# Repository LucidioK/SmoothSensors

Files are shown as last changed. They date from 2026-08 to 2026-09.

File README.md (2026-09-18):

# SmoothSensors03

This is a simple robot that responds to these voice commands:

*  Go ahead
*  Go back
*  Turn right
*  Turn left
*  Stop
*  Calibrate (spins the robot in place to correct compass bias — see [Basic Functionality](#basic-functionality))
*  Point to <bearing> (North, Northeast, East, Southeast, South, Southwest, West, Northwest — turns the robot in place to face the requested absolute heading, using the calibrated compass — see [Basic Functionality](#basic-functionality))  
All its code is in this repository, including all files to 3D print its chassis.

[Here is a short video with it in action.](https://www.youtube.com/shorts/1sfNaSUcYxk)

## Bill of materials

* Arduino Uno Q
* NASTIMA 6V 6Ah LiFePO4 Battery with USB C Charge
* Arduino Modulino Motors ABX00114
* Arduino Modulino Buttons ABX00110
* Arduino Modulino Distance ABX00102
* Arduino USB-C Hub (8 in 1) TPX00241
* DC Electric TT Prewired Gear Motor Wheel Kit 3-6V Dual Shaft Geared
* I2C Qwiic Cable Kit Stemma QT Wire
* USB Camera Module 640x480 30FPS Wide Angle 170° HD Vision Module for Robot Building DIY Webcam Board for Arduino
* M2, M2.5 and M3 bolts.
* Caster whell, 50mm tall.

## Software

* [Arduino CLI](https://github.com/arduino/arduino-cli/releases)
* [Arduino App Lab](https://docs.arduino.cc/software/app-lab/)
* [VS Code](https://code.visualstudio.com/download)

## The chassis

Folder `cad` has the 3D model and the 3D print files for the chassis that accommodates all parts.

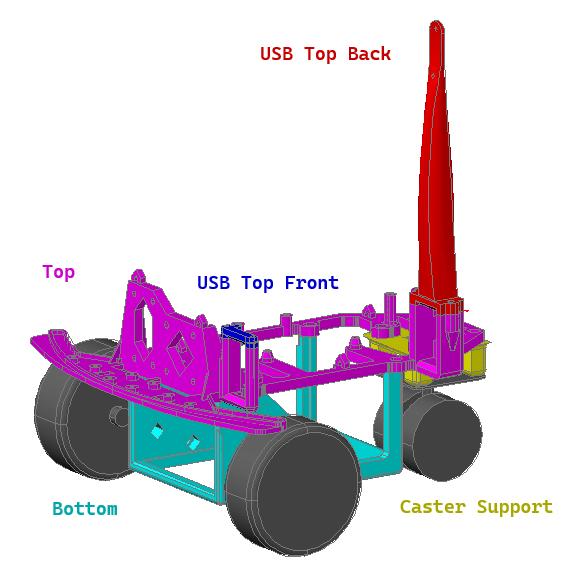
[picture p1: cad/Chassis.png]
Chassis


The chassis was optimized to use as little material and to print as fast as possible. As such, it is composed of five parts:

| Part | Part File | Description |
|---|---|---|
| Top | RobotChassis03Top.stl | where the Arduino and the sensors are attached. |
| Bottom | RobotChassis03Bottom.stl | where the battery and the motors are attached. |
| UsbB | RobotChassis03UsbB.stl | The top of the USB hub harness, back part, also where Mic and Camera should be attached. |
| UsbF | RobotChassis03UsbF.stl | The top of the USB hub harness, front part.  |
| Caster Support | RobotChassis03CasterSupport.stl | to be attached to the Top, then the caster wheel will be attached to. |

* File [RobotChassis03Split.dwg](cad/RobotChassis03Split.dwg) is the 3D model, it was done in AutoCAD.
* File [RobotChassis03.3mf](cad/RobotChassis03.3mf) is the Creality print file for all the parts in one print.
* File [RobotChassis03.stl](cad/RobotChassis03.stl) is the full assembled chassis as a single mesh, provided so it previews directly on GitHub (the split part files above don't render individually).
* File [Chassis.png](cad/Chassis.png) is the rendered preview image shown above.

## Repository structure

This is an [Arduino App Lab](https://docs.arduino.cc/software/app-lab/) project: an MCU-side sketch and a Linux-side Python app that run simultaneously on the Uno Q and talk to each other over RPC.

* `app.yaml` — the App Lab manifest that ties the `sketch/` and `python/` halves together into a single deployable app (`SmoothSensors03`).
* `SPEC.md` — the full project specification (hardware, architecture, behaviors, safety interlocks) for the robot, including parts not yet built.
* `PHASE1.md` — the current build phase broken into ordered, individually testable scenarios (non-vision voice commands, motors, safety), scoped down from `SPEC.md`.
* `test.py` — runs the whole test suite: `python/tests/` (always safe), then `sketch/tests/test_sketch_hardware.py` (a no-op dry run unless `--yes` is passed). Extra CLI args are forwarded to the sketch test, e.g. `python test.py --yes`.

### `sketch/` — MCU-side C++ program (Zephyr RTOS)

| File | Description |
|---|---|
| `sketch.ino` | Main entry point. Wires up the sensors/actuators, exposes `show_text` and `move` to Python over `Bridge`, and drives the main loop (record sensor samples every iteration, print status to the Serial Monitor once a second, auto-stop when an obstacle is closer than 10cm). Also handles the `calibrate` `move` command: delegates to `CombinedCalibration`, which runs motor calibration then compass calibration in sequence (replacing the former separate `calibrate_motors`/`calibrate_compass` commands). Also handles the 8 `point_*` `move` commands (one per bearing): a turn/settle/re-check loop closes on `SmoothCompass::getDirectionAngle()` until the heading is within ±8° of the target or an 8s timeout elapses, refusing to run (`e06`) unless `CompassCalibration` reports a calibration has already succeeded this boot. Also handles the `compass_mode` `move` command, delegating to `CompassMode`. |
| `SmoothDistance.h` | Wraps the `ModulinoDistance` (VL53L4 time-of-flight) sensor in a circular buffer that averages readings after dropping the min/max outlier, exposed via `getDistanceCm()`. |
| `SmoothMovement.h` | Same outlier-rejecting smoothing technique as `SmoothDistance.h`, applied to the `ModulinoMovement` IMU; exposes smoothed accelerometer and roll/pitch/yaw via `get(...)`. |
| `SmoothCompass.h` | Same outlier-rejecting smoothing technique, applied to the `Adafruit_LIS3MDL` magnetometer; exposes heading via `getDirectionAngle()`/`getDirectionBearing()`. Raw readings are hard-iron biased (onboard motor/battery/wiring magnetism), so it also tracks raw min/max during a calibration window (`startCalibration()`/`finishCalibration()`) to compute and apply an offset/scale correction. `getDirectionAngle()` now also drives the closed-loop absolute-heading turns behind the `point_*` commands, not just calibration. Includes a `recoverBus()` I2C bus-recovery guard run before any sensor transaction, to fail safely instead of hanging the board on a stuck bus. |
| `CompassCalibration.h` | Drives the motor-powered, gyro-closed-loop calibration spin, run as the second phase of the `calibrate` command: spins the robot in place via `RobotMotors`, integrating the IMU's `rz` to track rotation until it passes 380° (a 20° overshoot margin) or an 8s timeout elapses, then — if it actually rotated at least 300° — hands the spin off to `SmoothCompass::finishCalibration()` to compute the offset/scale correction. Fully self-contained: owns its own sensor reads and Monitor/LED reporting. |
| `MotorCalibration.h` | Runs as the first phase of the `calibrate` command: ramps turn power to find and store a reliable turn speed, plus each direction's steady-state rate and momentum-coast angle (used by `RobotMotors` to compensate point-to-bearing turns for overshoot). Fully self-contained, same shape as `CompassCalibration.h`. |
| `CombinedCalibration.h` | Sequences `MotorCalibration` then `CompassCalibration` behind the single `calibrate` command (GitHub issue #6) — pure orchestration, no sensor/display access of its own since both sub-features already own their own reporting. |
| `CompassMode.h` | Continuously displays the compass bearing on the LED matrix while active (GitHub issue #12). Cancelled by `SketchClass` whenever any other text is shown on the LED matrix. |
| `RobotMotors.h` | Wraps the `ModulinoMotors` dual H-bridge driver; translates command strings (`go_ahead`/`go_back`/`turn_right`/`turn_left`/`stop`) into motor drive calls and reports status via `getStatus()`. While `go_ahead`/`go_back` are driving, continuously reads the gyro's yaw rate and nudges a live per-wheel correction to hold a straight line against the free-swiveling rear caster's drift (GitHub issue #10). |
| `LedMatrixDisplay.h` | Wraps the Uno Q's built-in 8x13 LED matrix (`ArduinoLEDMatrix`) to print short (3-character) status codes, e.g. `rdy`, `ga`, `st`. |
| `sketch.yaml` | Pins the `arduino:zephyr` platform and exact versions for every Arduino library the sketch depends on (Modulino, RouterBridge, LSM6DSOX, LIS3MDL magnetometer, etc.), so profile-based builds don't depend on globally installed libraries. |
| `tests/test_sketch_hardware.py` | **Hardware-in-the-loop test — deploys to and restarts a real robot.** Runs `scripts/deploy.sh`/`deploy.ps1` to build+upload the sketch, then reads back `arduino-app-cli monitor` (the MCU's own Serial output) and `arduino-app-cli app logs` (the Python app's stdout — a separate stream, captured sequentially rather than concurrently so two SSH password prompts don't race) over SSH, asserting each sensor/motor class (`SmoothDistance`, `SmoothMovement`, `RobotMotors`) is reporting status without crashing the loop. Does nothing unless you pass `--yes`; see the file's docstring for usage and safety notes. |

### `python/` — Linux-side Python app (`arduino.app_utils` App framework)

| File | Description |
|---|---|
| `main.py` | App entry point. Polls `VoiceCommands` for a recognized command each loop iteration and forwards it to the MCU side via `Bridge.call("show_text", ...)` and `Bridge.call("move", ...)`. |
| `VoiceCommands.py` | Offline voice recognition using Vosk, grammar-constrained to the wake word "robot" followed by one of the move commands (`go ahead`/`go back`/`turn right`/`turn left`/`stop`/`calibrate`/`compass mode`/`point to north`/`point to northeast`/`point to east`/`point to southeast`/`point to south`/`point to southwest`/`point to west`/`point to northwest`). Captures audio by spawning `arecord` as a subprocess (not PyAudio, since the board's venv has no C compiler to build native extensions) and feeds the raw PCM to the recognizer. |
| `requirements.txt` | Python dependencies for the Linux side (currently just `vosk`, the offline speech recognizer). |
| `model/` | *(not checked in, gitignored)* The Vosk speech model, tens of MB. Uploaded once by `scripts/deploy.sh` the first time it's missing on the board, then left alone on subsequent deploys. |
| `tests/test_python_app.py` | Unit tests for `VoiceCommands.py` and `main.py`. Runs off-board by stubbing `vosk`, `arduino.app_utils`, and the `arecord` subprocess. Run with `python -m unittest discover -s python/tests -v`. |

### `scripts/` — deploy and diagnostic tooling

| File | Description |
|---|---|
| `deploy.sh` | Pushes `sketch/`, `python/` (except `python/model/`), and `app.yaml` to the board over `tar`+`ssh`, then restarts the app via `arduino-app-cli`. Run from Linux/Mac/WSL. |
| `deploy.ps1` | Windows PowerShell equivalent of `deploy.sh`; auto-detects the board's IP address. |
| `setup_ssh_key.py` | Sets up passwordless SSH access to the board (the actual "ssh-copy-id" step — reuses `~/.ssh/id_ed25519` if you have one, otherwise generates a dedicated key, then appends the public key to the board's `~/.ssh/authorized_keys`). Run once before using `deploy.sh`/`deploy.ps1`; prompts for the board's password one last time. Safe to re-run. |
| `diagnose_usb_mic.sh` | Diagnoses (and, with `--fix`, attempts to repair) USB host / microphone enumeration problems on the board's Linux side — e.g. forcing the board's dual-role USB-C port into host mode so a hub/mic enumerates correctly. Must be run **on the board**, not the PC (it inspects local kernel/sysfs USB state). Can be piped over SSH without copying it to the board first: `ssh <board-user@host> 'bash -s' -- --fix < scripts/diagnose_usb_mic.sh`. |

## If you are using WSL (Windows System for Linux)

WSL runs in a VM without full access to the network.

As such, there is one Arduino CLI command that does not work on WSL: 

```bash
arduino-cli board list
```

If you are in Windows using WSL, you will need to run that command in a Powershell/cmd prompt.

## How to deploy

1. First, you need to initialize the Arduino board. Make sure you followed the [Initial Setup instructions](https://docs.arduino.cc/software/app-lab/setup/overview) for [Single Board Computer](https://docs.arduino.cc/software/app-lab/setup/standalone) mode.
1. After your Arduino Q is connected to your network, you will always use it through the network, the provided deploy scripts assume the board is already network bound.
1. Set up passwordless SSH access to the board (the deploy scripts call `ssh` non-interactively, which doesn't work with password auth): run `python scripts/setup_ssh_key.py` once (or `python scripts/setup_ssh_key.py arduino@<board-ip>` if it's not at the default address). You'll be prompted for the board's password one last time.
1. About the board's IP address:
   1. If you are using Windows with Powershell, you can use `scripts/deploy.ps1`, it automatically detect the board's IP address.
   1. Otherwise, you will need to discover the board's IP address and configure `scripts/deploy.sh` to point to the address:
      1. If you are using WSL, open a Powershell command prompt, if you are on Linux or Mac, open a command prompt.
      1. Run:
         ```
         arduino-cli board list
         ```
      1. If your robot is on and connected to the same network as your computer, you will see an output similar to this:
         ```
         Port       Protocol Type              Board Name    FQBN                Core
         10.0.0.221 network  Network Port      Arduino UNO Q arduino:zephyr:unoq arduino:zephyr
         ```
      1. The four numbers under `Port` are the IP address from your robot.
      1. Edit `scripts/deploy.sh` and replace the IP in this line with your robot's IP address:
         ```
         BOARD_IP="${1:-${BOARD_IP:-10.0.0.195}}"
         ```
      1. Save and close `scripts/deploy.sh`.
4. Now you can deploy the application:
   1. On Windows:
      1. Open a Powershell command prompt, 
      1. Go to the folder where you cloned this repository,
      1. Execute:
         ```powershell
         ./scripts/deploy.ps1
         ```
   1. On Linux/Mac/WSL
      1. Open a Powershell command prompt, 
      1. Go to the folder where you cloned this repository,
      1. Execute:
         ```bash
         ./scripts/deploy.sh
         ```

## Basic Functionality

```mermaid
stateDiagram-v2
    [*] --> Ready
    Ready --> GoAhead: Voice detected go ahead
    Ready --> GoBack: Voice detected go back
    Ready --> TurnRight: Voice detected turn right
    Ready --> TurnLeft: Voice detected turn left          
    Ready --> Calibrate: Voice detected calibrate
    Ready --> Point: Voice detected point to bearing
    Ready --> CompassMode: Voice detected compass mode
    GoAhead --> Stop: Voice detected STOP or distance less than 10cm
    GoBack --> Stop: Voice detected STOP or distance less than 10cm
    TurnRight --> Stop: Voice detected STOP or distance less than 10cm
    TurnLeft --> Stop: Voice detected STOP or distance less than 10cm
    Calibrate --> Ready: Spin reaches 380° or 8s timeout elapses
    Point --> Ready: Heading reaches target or 8s timeout elapses
    CompassMode --> Ready: Any other text shown on the LED matrix
    Stop --> Ready

```

## Error codes

When something goes wrong, the LED matrix shows a short `eN` code instead of the usual `ok`/command-echo status. Meanings:

| Code | Meaning |
|---|---|
| `e1` | The motors failed to initialize at startup, or a voice command arrived before/without them being ready. |
| `e2` | `robot calibrate` was requested, but the compass, movement sensor, or motors aren't initialized. |
| `e3` | A calibration spin finished but didn't detect enough rotation (or a wide enough magnetic swing) to compute valid correction values — most likely the robot didn't actually spin (stuck, lifted, or interrupted too early). |
| `e4` | `robot point to <bearing>` timed out (8 seconds) before the robot's heading reached the target bearing. |
| `e5` | `robot point to <bearing>` was requested, but the compass, movement sensor, or motors aren't initialized. |
| `e6` | `robot point to <bearing>` was requested before any compass calibration has succeeded since the robot last booted — run `robot calibrate` first. |
| `e7` | `robot calibrate` was requested, but a required sensor/motor isn't initialized (movement sensor or motors). |
| `e8` | `robot calibrate`'s motor calibration turn-power ramp failed to detect movement. |
| `e9` | `robot compass mode` was requested, but the compass sensor isn't initialized. |

`e01` is reserved in `SPEC.md` for a "find and follow \<object\>" voice command that isn't implemented yet, so it can't appear on the robot today.

## Known issues

1. (Arduino default behavior) the application must be redeployed every time the board is restarted.
1. When the robot is moving, due to the noise of the motor, the voice commands are not well understood. You need to talk much louder or close to the mic, depending on the quality of the microphone you are using. This has been greatly mitigated with the new USB
1. After the robot detects it is in less than 10 centimeters of some obstacle, it does not move. You say `robot go ahead` and it will move for half a second, at the most. In that case, place your hand in front of the distance sensor and move away. 
1. I am using very low quality motors, so some motors move faster than others despite being fed the same tension and current. I recommend you buy many motors, then test them and get motors with similar RPM when fed 5V.

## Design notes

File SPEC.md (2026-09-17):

# SmoothSensors Robot — Specification (Draft v1)

Status: DRAFT — under active review. Items marked TBD still need a decision before the phase that depends on them.

## 1. Purpose

An autonomous, wheeled robot that responds to voice commands, including finding and following an object (e.g. a person, a car, a cat) using onboard computer vision. No manual/remote-control mode in v1 — voice is the only control input. All commands are prefixed with the wake word "robot"; any speech not starting with "robot" is ignored.

## 2. Hardware

| Component | Role | Status |
|---|---|---|
| Arduino UNO Q | Dual-brain controller: Qualcomm QRB2210 (Linux, quad-core Cortex-A53 @ 2GHz, Adreno GPU) + STM32U585 (Zephyr RTOS, Cortex-M33) | Have it |
| Modulino Distance | Front-facing time-of-flight distance sensor | Wired, code exists (`SmoothDistance.h`) |
| Modulino Movement | IMU (accelerometer + gyro) | Wired, code exists (`SmoothMovement.h`) |
| Modulino Motors | MAX22211 dual H-bridge driver, 2 DC motors, differential drive, 5–24V/3.8A per channel motor supply, I2C/Qwiic control. Has configurable current-drive regulation (ITRIP, set via REFA/REFB resistors, up to 3.8A) — used to current-limit each motor channel, see Power row below. | Have it, not yet wired |
| Motors | [TT gear motor wheel kit](https://www.amazon.com/dp/B098Q1BCX5) (generic "TT motor," 1:48 gearbox, dual shaft, 69mm wheels). Standard TT motor specs: **rated 3–6V**, ~150mA no-load current per motor, ~1.1–1.5A stall current per motor (varies with voltage), ~200 RPM / 0.8 kg·cm stall torque at 6V. | Chosen |
| Magnetometer (LIS3MDL) | `"robot turn right/left N degrees"` still uses relative gyro dead-reckoning, not the compass (see §4). But absolute heading **is** now used, for `"robot point to <bearing>"` (§4c) — a real v1 use case, not deferred as originally planned (see §7 item 2). | **Wired, calibrated, and in active use.** `sketch/SmoothCompass.h` is wired into `sketch.ino`/the RPC surface and reads real hardware (no boot-hang — the `recoverBus()` guard holds). Raw headings were hard-iron biased (~3x Earth's field, confirmed empirically) until the motor-driven, gyro-closed calibration spin (§4b) was added and run — calibrated headings are now accurate enough to drive closed-loop turns (§4c). |
| USB camera | Front-facing; dual purpose: (a) input to onboard object-detection model, (b) live view streamed to a human over the local network. No built-in mic. | Physically present, not yet wired |
| Microphone | Captures voice commands | Mini USB microphone, attaches to the USB-C hub alongside the camera. Plugs into the Linux side, no custom MCU-side driver work. Purchased. **STT engine: Vosk** (offline, on-device) — no network dependency for core voice commands, lightweight enough for the QRB2210. |
| USB-C hub | The UNO Q has exactly **one USB-C port and no built-in USB-A ports**, so the camera and mic can't both plug in directly — a hub is required. Recommendation: **Arduino's official 8-in-1 USB-C hub for UNO Q** (USB-A 2.0, USB-A 3.0, HDMI, Ethernet, and — critically — **power delivery passthrough**, so the board still receives power through the hub while the camera and mic occupy its USB-A ports). A hub without PD passthrough would leave the board without a power path once the port is used for peripherals. | Purchased |
| Onboard LED matrix | Built into the UNO Q (8×13, 104 LEDs), driven by the STM32 MCU via the `Arduino_LED_Matrix` library. Used as the robot's only feedback display — see §4. | Built-in, have it |
| Chassis | Current: prototype. Target: 3D-printed. | Tracked as a separate design track (own mini-spec: dimensions, mount points, clearances) once electronics layout is settled — not part of this software spec. |
| Power | **Two separate rails**: one for Uno Q logic (delivered via the USB-C hub's power passthrough), one dedicated battery+regulator feeding the Modulino Motors' screw terminals directly. Avoids brownouts from motor current sagging the logic supply. Mitigation: set the MAX22211's ITRIP current limit to ~1.5A per channel (matching the motors' rated stall current) to cap heat/mechanical stress during stall. No PWM duty-cycle cap needed — the UBEC (below) holds motor rail voltage at a clean, fixed 6.0V regardless of battery charge state, so the driver never sees more than the motors' rated 6V. | [NASTIMA 6V 6Ah LiFePO4](https://www.amazon.com/dp/B0FD3SZFXF/) (2000+ cycles, built-in BMS, 10A max continuous discharge — well above the ~3A worst-case combined motor stall current) feeding a [Hobbywing 5A UBEC](https://valuehobby.com/hobbywing-5a-ubec-high-voltage.html) (switching buck regulator, output fixed to 6.0V, 5A continuous/15A instantaneous, >90% efficient) wired between the battery and the Modulino Motors' screw terminals. Raw battery voltage swings ~5–7.3V across its charge cycle (LiFePO4 cells read above 6V nominal near full charge); the UBEC clamps that to a steady 6.0V so the motors (rated 3–6V) never see an overshoot, eliminating the need for a software PWM cap. Battery-to-UBEC wiring: solder a cable from the NASTIMA's output connector to the UBEC input directly — no off-the-shelf connector match needed. Rejected earlier: [WAVYPO 9V 1300mAh Li-ion](https://www.amazon.com/dp/B0BC8P2TS6) — reviews report its internal boost converter caps steady-state output around ~100mA, far below driving current needs. | Purchased |
| Motor voltage regulator | [Hobbywing 5A UBEC](https://valuehobby.com/hobbywing-5a-ubec-high-voltage.html) — steps the LiFePO4 battery's raw ~5–7.3V down to a fixed, regulated 6.0V for the motor rail. See Power row. | Purchased |

## 3. System architecture

Two-brain split, mirroring the UNO Q hardware:

- **MCU side** (`sketch/`, Zephyr, real-time) — owns the Modulino I2C bus: Distance, Movement, Motors (Magnetometer deferred to phase 2, see §2). Responsible for low-level motion primitives (drive, turn-by-degrees, stop) and **hard safety interlocks** (tilt-stop, proximity-stop), enforced locally so they still fire even if the Linux side is slow or busy. Exposes primitives to the Linux side over RPC (extending the existing but currently-empty `get_sensor_values()` bridge).
- **Linux side** (`python/`, Debian, "brain") — owns the camera, microphone, speech-to-text (Vosk, offline), object-detection model, the local-network video stream server, and the high-level behavior loop (filter for the "robot" wake word → interpret voice command → decide behavior → issue motion requests to the MCU side). Never drives motors directly.

**Why split safety this way**: if proximity-stop and tilt-stop lived only in Python, a slow CV inference frame could delay a stop. Putting them on the MCU side is defense-in-depth — the robot stops even if the "brain" is momentarily busy.

## 4. Core behaviors

- **Voice-driven, fully autonomous.** No joystick/remote mode in v1.
- **Wake word:** every command must start with the word "robot" (e.g. "robot stop", "robot find and follow cars"). Any recognized speech that doesn't start with "robot" is discarded — no action taken, no side effects.
- **v1 command vocabulary:**
  - `"robot find and follow <object>"` → enter autonomous vision-following mode targeting the named object class (e.g. "cats", "people", "cars" — not limited to a fixed list, see below)
  - `"robot stop"` → halt all motion, exit any active mode
  - `"robot go forward"` → drive straight forward in a line
  - `"robot turn right <N> degrees"` / `"robot turn left <N> degrees"` → closed-loop turn using gyroscope feedback: integrate the Modulino Movement IMU's Z-axis rotation rate (`rz`, already exposed by `SmoothMovement::get()`) over time to track cumulative rotation since the turn started, stop once it reaches `N` degrees. No magnetometer needed — v1 turns are relative (dead-reckoned), not absolute-heading; drift over the few seconds a turn takes is negligible. See §2, Magnetometer row.
  - `"robot calibrate"` → triggers motor calibration followed by the compass calibration spin, in that sequence (MCU-side `move("calibrate")` command) → see §4b.
  - `"robot point to <bearing>"`, where `<bearing>` is one of North/Northeast/East/Southeast/South/Southwest/West/Northwest → closed-loop turn using the live, calibrated compass heading (not gyro dead-reckoning) to rotate until the robot faces the requested absolute bearing → see §4c.
  - This is the full v1 vocabulary planned so far; more can be added in a later phase once the core loop is proven.
  - No backward-motion command in v1 — the only distance sensor is front-facing, so there's no obstacle protection for reversing. Revisit once a rear-facing sensor is added.
- **Go forward:** drives continuously until `"robot stop"` is heard or a safety interlock fires — same rule as following mode. No fixed-distance mode in v1.
- **Object-following mode:**
  - The target object name is parsed out of the command (the words after "find and follow") and mapped to a class the onboard object-detection model recognizes. A single general-purpose pretrained multi-class model (e.g. one trained on COCO, which already includes person, car, cat, dog, and more) covers this without per-object custom training — good fit given the requirement isn't cat-specific.
  - Name normalization: lowercase the parsed noun, strip a trailing "s" (handles "cats"→`cat`, "cars"→`car`, "dogs"→`dog`, etc.), with a small hand-written exception table for irregulars (starting with "people"→`person`), extended as new irregular cases come up. No NLP library dependency.
  - If the requested object isn't a class the detector supports (e.g. "robot find and follow squirrels"), display error `e01` on the LED matrix (see §4a) instead of attempting the behavior.
  - Onboard object detection locates the target class in the camera frame; robot steers to keep it centered and drives toward it.
  - Stop distance from the target: reuses the proximity-stop threshold (§5) — no special-cased "following distance," just don't get closer than the general obstacle-stop distance.
  - Multiple matching objects in frame: follow whichever detected instance has the largest bounding box (a simple proxy for "closest/most prominent," needs no extra hardware); ignore the rest.
  - Lost target: rotate in place toward the side the target was last seen, sweeping up to a full 360°, to search and reacquire. If the target isn't reacquired by the time the sweep completes, stop and await a new voice command — the full rotation itself bounds the search, no separate timeout needed.
- **Live camera view:** streamed over the local Wi-Fi network for a human to watch. Observation only — never used as a control input by the human.

## 4a. Feedback display (onboard LED matrix)

The robot's only user-facing feedback channel in v1 is the built-in LED matrix (no speaker/TTS in scope):

- **Understood a command:** display `ok`.
- **Any error:** display `eNN`, where `NN` is a two-digit error code.
- **Error code registry** (extend as new error cases are identified during implementation):
  | Code | Meaning |
  |---|---|
  | `e01` | Requested object class not recognized by the detector |
  | `e02` | Compass calibration requested but a required sensor/motor isn't initialized |
  | `e03` | Compass calibration finished but the magnetic sample span was too small to compute valid offsets (likely didn't actually rotate) |
  | `e04` | Point-to-bearing timed out (8s) before reaching the target heading within tolerance — see §4c |
  | `e05` | Point-to-bearing requested but a required sensor/motor isn't initialized (mirrors `e02` for the point-to command) |
  | `e06` | Point-to-bearing requested before any compass calibration has succeeded this boot — see §4c |
- **In-progress status codes** (extend as new commands are added): `rdy` (ready at startup), `ga`/`gb`/`tr`/`tl`/`st` (go ahead / go back / turn right / turn left / stop, echoing the recognized command), `cal` (calibration succeeded), `pN`/`pNE`/`pE`/`pSE`/`pS`/`pSW`/`pW`/`pNW` (point-to-bearing in progress, shown immediately on command receipt — see §4c).
- **Persistence:** the matrix shows the result of the last command and stays that way until the next command overwrites it — no auto-clear timer. Before the first command is ever received, the matrix is blank.

Since the LED matrix hardware is driven by the MCU (`Arduino_LED_Matrix`) but recognition/parsing happens on the Linux "brain," the Linux side will need to request a display update from the MCU side over RPC (alongside the existing motion-primitive RPC calls in §3).

## 4b. Compass calibration (motor-driven, gyro-closed)

The magnetometer readings are dominated by a hard-iron offset from onboard magnetic material (motors, battery, wiring) — raw headings only sweep a narrow ~40° arc instead of the full circle. Calibration removes this by finding the offset (and axis scale, for soft-iron distortion) from a full-circle sample of raw x/y readings, then correcting all future readings against it.

- **Trigger:** voice command `"robot calibrate"` (added to the Vosk grammar in `python/VoiceCommands.py` alongside the existing move commands), which calls the MCU-side `move("calibrate")` RPC (same RPC surface as `go_ahead`/`turn_right`/`turn_left`/`stop`, see §3) — this runs motor calibration first, then the compass calibration spin described below, as a single sequenced command.
- **Rotation:** self-driven via the existing motors, not manual. Closed-loop on the gyro, using the same `rz`-integration dead-reckoning technique described for `turn right/left N degrees` (§4) — this calibration spin is the first actual implementation of that technique in the sketch; `turn right/left N degrees` itself remains unimplemented (§4 documents the intended approach only). Accumulate rotation until it passes **380°** (a 20° overshoot margin over a full circle, to absorb gyro lag/undershoot so no heading is missed), then stop. A **hard timeout (8s)** force-stops the motors regardless of accumulated angle, guarding against the robot being stuck or lifted mid-spin, where `rz` would never accumulate.
- **Safety interlock:** the proximity-stop check (§5) is suspended for the duration of calibration — it's a pure in-place spin, not forward motion — and restored once calibration ends (success or timeout).
- **Sampling:** raw magnetometer x/y are tracked (min/max per axis) throughout the spin, alongside the existing smoothed ring buffer.
- **Result:** hard-iron offset (`(max+min)/2` per axis) and soft-iron scale (`mean_radius / ((max-min)/2)` per axis) are computed once the spin ends, applied immediately in RAM (so `SmoothCompass::getDirectionAngle()` is corrected for the rest of that boot), and printed to the Monitor for the operator to copy into `SmoothCompass.h` as permanent defaults — there's no flash/EEPROM persistence in this codebase, so an in-RAM-only calibration is lost on reboot until hardcoded.
- **Not addressed by this calibration:** the dynamic field from motor current while driving (differs from the field during the calibration spin itself), and any residual mounting-rotation/declination offset — both remain open, see §7.

## 4c. Point to bearing (closed-loop compass turn)

Turns the robot in place until it faces a requested absolute bearing, using the live, calibrated compass heading as feedback rather than gyro dead-reckoning (unlike §4b's calibration spin, which has no absolute reference to close the loop against, this command's whole purpose is to use one).

- **Trigger:** voice command `"robot point to <bearing>"` for one of the 8 primary bearings (North/Northeast/East/Southeast/South/Southwest/West/Northwest), added to the Vosk grammar in `python/VoiceCommands.py`. Each maps to a distinct RPC command string: `point_north`, `point_northeast`, `point_east`, `point_southeast`, `point_south`, `point_southwest`, `point_west`, `point_northwest`. Target degrees: N=0°, NE=45°, E=90°, SE=135°, S=180°, SW=225°, W=270°, NW=315°.
- **Precondition, runtime-enforced:** a compass calibration (§4b) must have succeeded at least once since boot. This is checked in code (not just documented) — a `point_*` command issued before any successful calibration this boot is refused with error `e06`, rather than silently running against whatever `SmoothCompass.h`'s hardcoded defaults happen to be.
- **Display:** immediately on receiving the command (before the turn starts), the LED matrix shows `p` followed by the bearing's abbreviation (`pN`, `pNE`, `pE`, `pSE`, `pS`, `pSW`, `pW`, `pNW`) — this is the Python-side `main.py` `_led_codes` entry, shown the same way `ga`/`tr`/etc. are today. On completion, the MCU overwrites it with `ok` (reached the target) or `e04` (timed out).
- **Direction decision:** compute the signed angular error (target − current heading, normalized to `(-180°, 180°]`). Turning right (`turn_right`) increases the reported heading (confirmed empirically against real hardware); a positive error turns right, a negative error turns left — the shorter way around, never more than 180° of rotation.
- **Turn/settle/re-check loop, not a single pass:** `SmoothCompass::getDirectionAngle()` is a 32-sample trim-mean, so while the robot is actively spinning the reported heading lags the true one — stopping the instant the raw error looks small would systematically overshoot. Instead: turn until the error is within tolerance (**±8°**) or its sign flips (guards against jumping past the tolerance band between loop iterations), stop the motors, wait for the ring buffer to refill with post-stop samples, then re-read the heading — if still outside tolerance, turn again (opposite direction if needed) rather than declaring success on a stale reading.
- **Safety timeout:** **8 seconds**, bounding the whole operation including every turn/settle/re-check cycle — guards against a bad calibration, an unreachable target, or oscillation at the tolerance boundary. Times out to `e04`.
- **Safety interlock:** proximity-stop (§5) is suspended for the duration, same reasoning as §4b — it's a pure in-place rotation, and the interlock's own `move("stop")`/LED-overwrite behavior would otherwise cancel the turn and stomp the `pN`-style display.
- **Cancellation:** any other `move()` command received while a point-to turn is in progress cancels it immediately (mirrors §4b's calibration-cancellation behavior). Re-issuing the same bearing while already turning toward it is a no-op (the turn continues); a different bearing restarts the turn toward the new target.
- **Not addressed:** a turn speed independent of the fixed drive speed used elsewhere (`RobotMotors`'s `DRIVE_SPEED`) — if physical testing shows the tolerance/settle values above don't converge reliably, a slower turn speed for this command specifically is the likely next step, deferred until shown necessary.

## 5. Safety (always active, MCU-enforced, overrides any in-progress command)

- **Proximity stop:** if the front distance sensor reads below a threshold, stop forward motion immediately. Threshold: **5 cm**.
- **Tilt stop:** IMU is monitored continuously (not just at startup); if tilt exceeds a threshold at any time, including mid-drive, stop all motion immediately. Threshold: **30°, provisional** — ships as-is in phase 1 (the chassis is built during phase 1, but calibrating this value is deliberately sequenced as a phase 2 activity, not blocked on anything from phase 1). **Phase 2 calibration:** physical test, tilting the assembled robot degree by degree until it tumbles, to find the real threshold — reusing the 30° provisional value until then.

## 6. Explicitly out of scope for v1

- Manual/remote teleoperation
- Camera used for anything beyond object-detection + human viewing
- Following objects outside the detector's supported classes
- Voice commands not prefixed with "robot"
- Chassis CAD (separate track)

## 7. Open items still needing a decision

1. Chassis dimensions/CAD (separate track, own spec)
2. ~~Whether v1 ever needs absolute heading (magnetometer) beyond relative turn-by-degrees~~ — resolved: yes, `"robot point to <bearing>"` (§4c) is a real v1 use case, built on the calibrated compass from §4b. Still open: a mounting-rotation/declination trim constant, and whether motor-current drift while actively driving needs separate handling (§4b's "not addressed" list) — neither has caused an observed problem yet since point-to only turns in place with motors idle otherwise
3. Final tilt-stop threshold — deferred to phase 2 by choice (empirical tumble test on the assembled robot), not blocked on chassis geometry since phase 1 builds the chassis
4. `"robot find and follow <object>"` (camera + onboard object detection) — deferred out of phase 1; camera isn't wired and no detection model is chosen yet. See `PHASE1.md` for phase 1's actual scope.
5. ~~Whether the calibration spin (§4b) should be exposed as a voice command~~ — resolved: yes, `"robot calibrate"` (§4/§4b)
6. Whether calibration constants need persistent (flash/EEPROM) storage, or hardcoding into `SmoothCompass.h` after each physical remounting remains acceptable

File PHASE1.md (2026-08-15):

# SmoothSensors — Phase 1

Status: DRAFT. Scope agreed 2026-08-14: non-vision commands only (`stop`, `go forward`, `turn <left|right> <N> degrees`), audio input, and LED matrix feedback, all backed by the MCU-side safety interlocks. No magnetometer, no camera/object-detection (`"find and follow"`) — those are deferred to a later phase (see `SPEC.md` §7). This file assumes `SPEC.md` as the source of truth for behavior/thresholds and only breaks it into buildable, testable steps.

Scenarios are ordered by dependency — each one after #2 can be built and manually tested standalone before the next.

## 1. Robot has an assembled physical chassis

- Gather real-world dimensions for every component that needs mounting, per `SPEC.md` §2: UNO Q board footprint, Modulino Motors module, TT motor + 69mm wheel kit, NASTIMA battery pack, Hobbywing UBEC, USB-C hub, USB camera, microphone, Modulino Distance sensor (needs a clear forward-facing view)
- Design the chassis as parametric FreeCAD Python scripts (`cad/`), driven by those dimensions — 4 bolted parts: top plate (sensors + UNO Q), battery box, and two motor mounts (left/right, below the battery)
- Render/export the design to STL via `cad/build_all.py` (`freecadcmd cad/build_all.py`)
- Obtain the 3D-printed parts (local printer or a print service)
- Assemble the chassis: mount the UNO Q board, Modulino Motors + motors/wheels, battery + UBEC, USB-C hub, camera, microphone, Distance sensor
- Basic tests: confirm physical fit (no interference between mounted parts, wheels turn freely by hand), confirm the chassis sits flat and stable at rest, confirm the board still boots and Distance/Movement sensors still read correctly once everything is mounted (checks for interference introduced by assembly, e.g. metal/wiring near the sensors)

## 2. Robot's motors are wired and powered

- Wire the Modulino Motors' screw terminals to the NASTIMA LiFePO4 battery via the Hobbywing UBEC, per `SPEC.md` §2 (Power row)
- Set the MAX22211's ITRIP to ~1.5A/channel via the REFA/REFB resistors
- Power on and confirm the board still boots normally and the Distance/Movement sensors still read correctly with the motor rail connected (check for brownout or I2C interference from motor switching noise)
- Bench-test: each wheel spins in both directions at a low duty cycle, driven by a throwaway test sketch (not the real primitives yet) — confirms wiring polarity and the driver chip before building on top of it

## 3. Robot's brain and controller can talk to each other

- Define the RPC message contract between `python/` and `sketch/` for: motion commands (`stop`, `driveForward`, `turn(direction, degrees)`) and LED display requests (`ok`, `eNN`)
- Implement the MCU-side RPC handlers in `sketch.ino`, extending the currently-empty `get_sensor_values()` bridge pattern
- Implement the Linux-side RPC client calls in `python/`
- Round-trip test: call a trivial RPC method from Python, confirm the MCU receives it and responds (e.g. echo or LED blink)

## 4. Robot stops on command

- Implement the `stop()` motion primitive on the MCU side (zero both motor channels)
- Wire it to the RPC handler from scenario 3
- Manual test: trigger `stop` via a hardcoded Python script call, confirm motors halt

## 5. Robot drives forward on command

- Implement the `driveForward()` motion primitive (both motors, same direction and duty cycle)
- Wire it to its RPC handler
- Manual test: trigger via script, confirm straight-line forward motion, confirm a follow-up `stop` call halts it

## 6. Robot turns left/right by a given number of degrees on command

- Confirm on real hardware whether `SmoothMovement`'s `rz` (from `_movement.getYaw()`) is an angular *rate* (°/s, as the code comment in `SmoothMovement.h` claims) or an already-integrated absolute angle — this determines whether the primitive needs to do its own time integration or can just read a running value. (No Modulino library source was available locally to confirm ahead of time.)
- Implement a dead-reckoned `turn(direction, degrees)` primitive: track cumulative rotation since the turn started (integrating `rz` over elapsed time if it's a rate) until it reaches the requested degrees, then stop
- Wire it to its RPC handler (direction + degrees as parameters)
- Manual test: trigger `turn right 90`, verify actual rotation against a physical reference mark (e.g. tape line on the floor), tune for overshoot/settling error

## 7. Robot stops automatically when something gets too close

- Implement a continuous MCU-side proximity check (5cm threshold, `SPEC.md` §5) that overrides any in-progress motion primitive, independent of RPC command cadence
- Manual test: drive forward via scenario 5, place an obstacle within 5cm, confirm the robot stops on its own with no Python-side involvement

## 8. Robot stops automatically when it tips too far

- Implement a continuous MCU-side tilt check using the existing `SmoothMovement` accelerometer data, provisional 30° threshold (`SPEC.md` §5) — this value ships as-is in phase 1; the degree-by-degree tumble test to find the real threshold is a phase 2 activity, not phase 1
- Same override behavior as scenario 7
- Manual test: tilt the assembled chassis past the (provisional) threshold mid-drive, confirm autonomous stop

## 9. Robot shows simple status messages on its LED matrix

- Add an `Arduino_LED_Matrix`-based display helper on the MCU side implementing `SPEC.md` §4a (`ok`, `eNN`, persists until overwritten, blank before the first command)
- Add the MCU-side RPC handler for display requests (from scenario 3's contract)
- Wire the Linux-side RPC call
- Manual test: trigger `ok` and a sample `eNN` from Python, confirm the matrix updates and persists

## 10. Robot receives orders by audio

- Integrate Vosk (offline STT) into `python/`: model selection/download, ALSA/PyAudio capture pipeline
- Continuous transcript loop; discard any utterance not starting with the wake word "robot" (`SPEC.md` §4)
- Command parser mapping recognized text to the phase 1 command set (`stop`, `go forward`, `turn <left|right> <N> degrees`) — reuse the object-name-normalization approach from `SPEC.md` §4 as a pattern, but only wire the non-vision commands now
- Any command outside the phase 1 set (including `"find and follow"`, deferred per scenario scope) or anything unparseable → trigger `eNN` on the LED matrix (scenario 9) instead of attempting the behavior
- Wire parsed commands to the RPC calls from scenarios 4–6
- Manual test: speak each phase 1 command aloud, confirm correct motion + LED feedback end-to-end

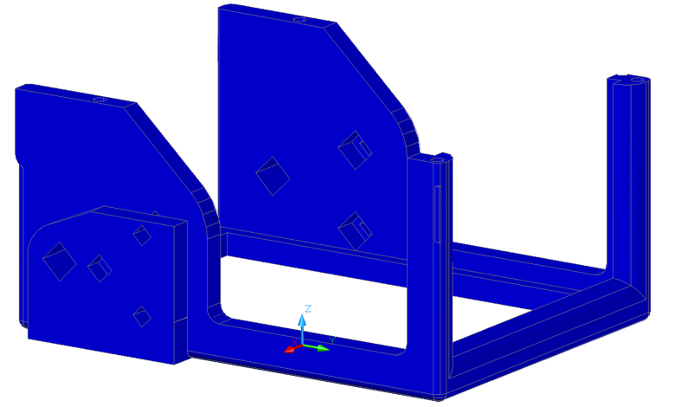
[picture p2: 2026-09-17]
cad/CurrentBottom.png

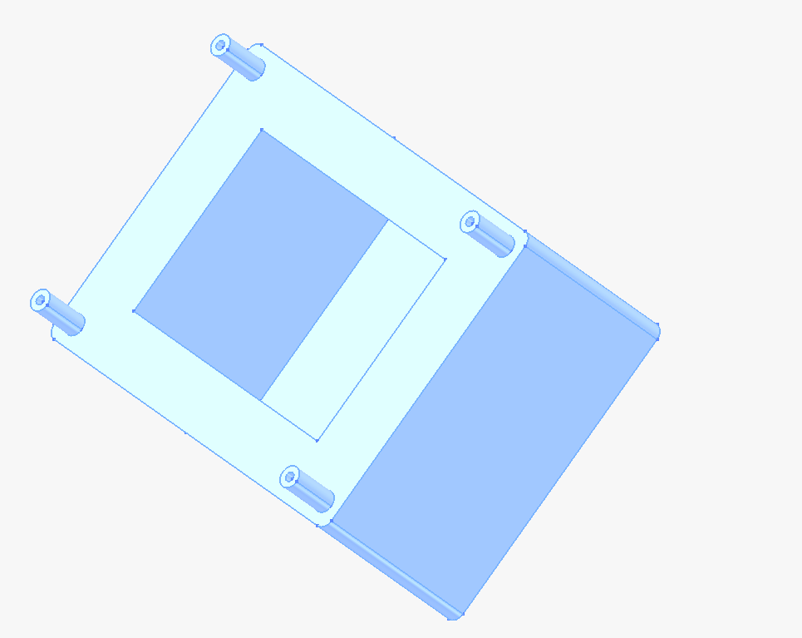
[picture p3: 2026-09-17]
cad/GeneratedBottom.png

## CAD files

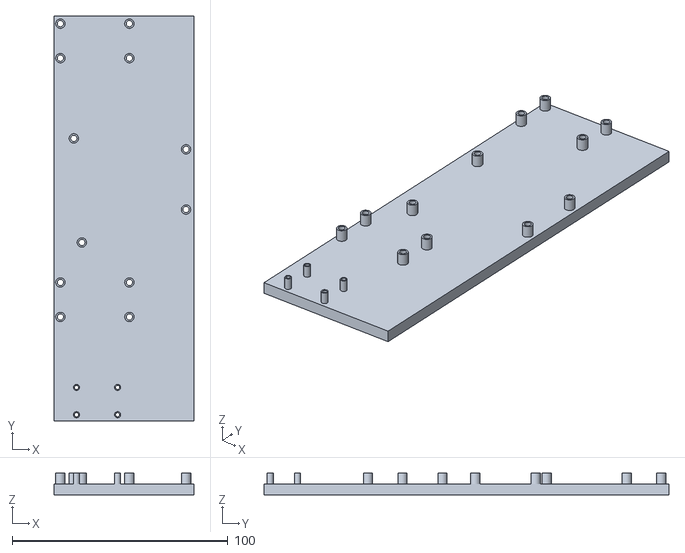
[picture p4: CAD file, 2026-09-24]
cad/top_plate-base_box.stl
64.8 x 187.8 x 10.0

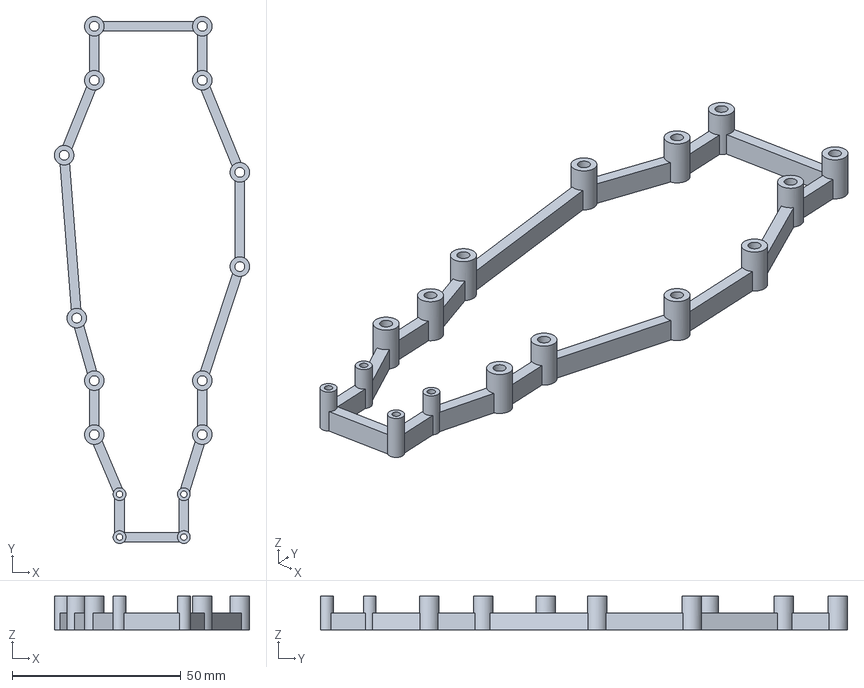
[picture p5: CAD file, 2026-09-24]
cad/top_plate.FCStd
57.9 x 156.1 x 10.0 mm

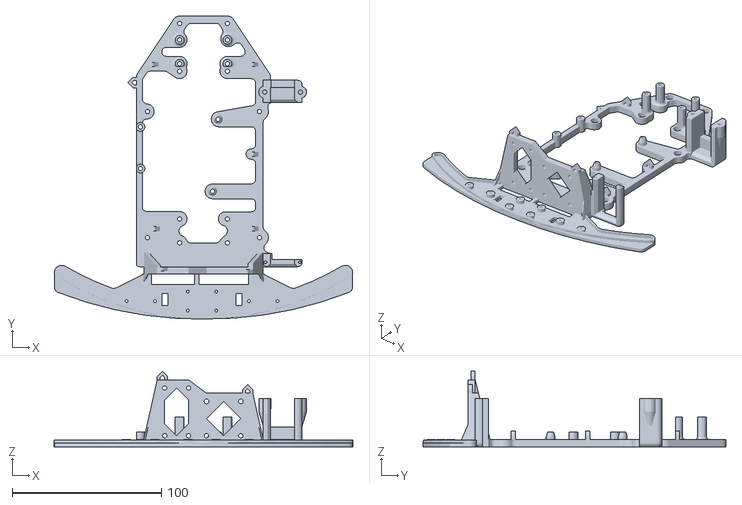
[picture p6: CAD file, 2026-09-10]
cad/RobotChassis03Top.stl
200.0 x 203.0 x 50.8

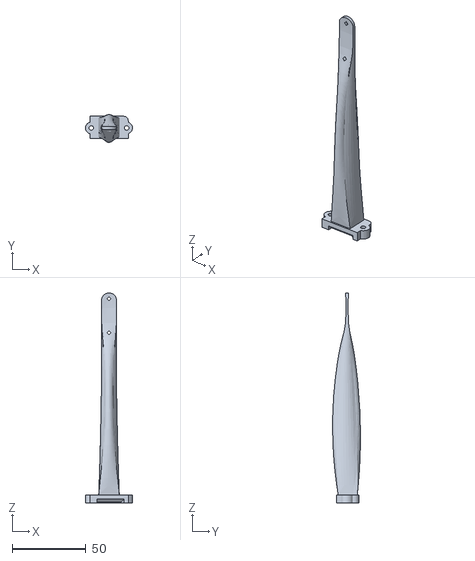
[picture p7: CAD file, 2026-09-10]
cad/RobotChassis03UsbB.stl
32.0 x 18.9 x 142.6

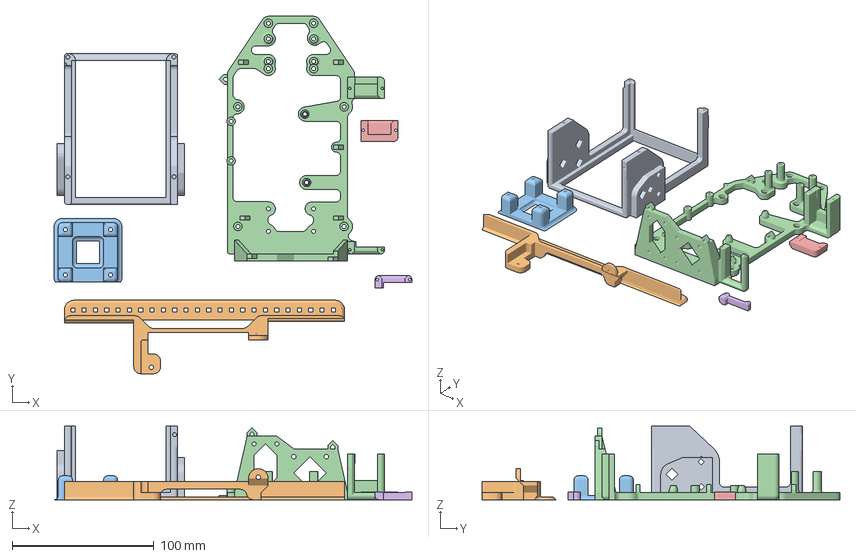
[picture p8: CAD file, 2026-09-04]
cad/RobotChassis03.3mf
252.8 x 252.6 x 52.0 mm
RobotChassis03Bottom.stl
RobotChassis03Bumper.stl
RobotChassis03CasterSupport.stl
RobotChassis03Top.stl
RobotChassis03UsbB.stl
RobotChassis03UsbF.stl

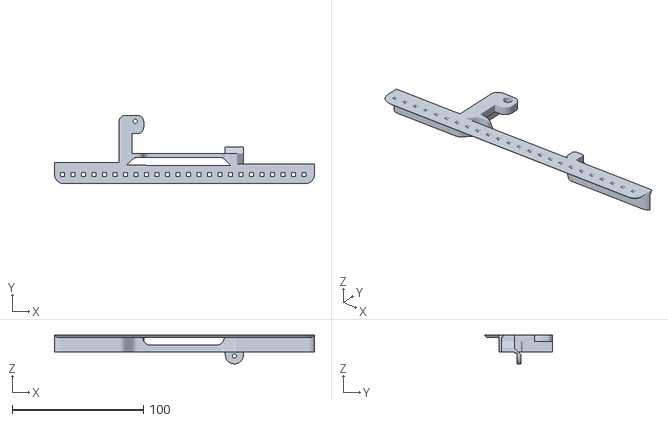
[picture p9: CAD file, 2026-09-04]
cad/RobotChassis03Bumper.stl
198.0 x 52.0 x 22.0

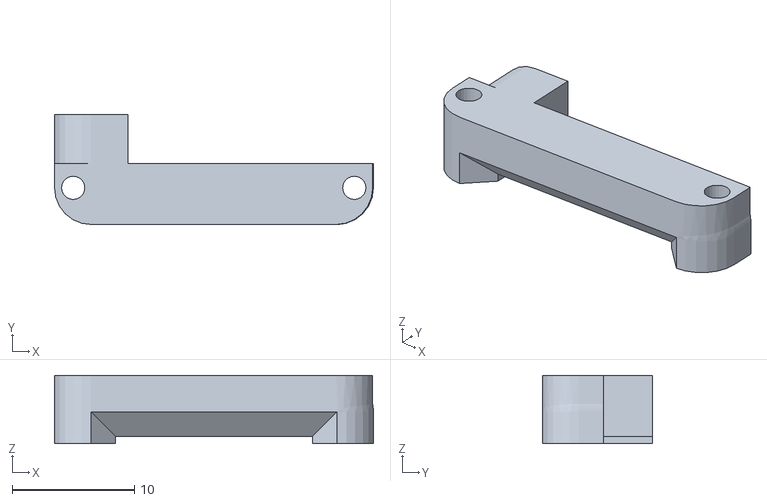
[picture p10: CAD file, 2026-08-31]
cad/RobotChassis03UsbF.stl
26.1 x 9.00 x 5.60

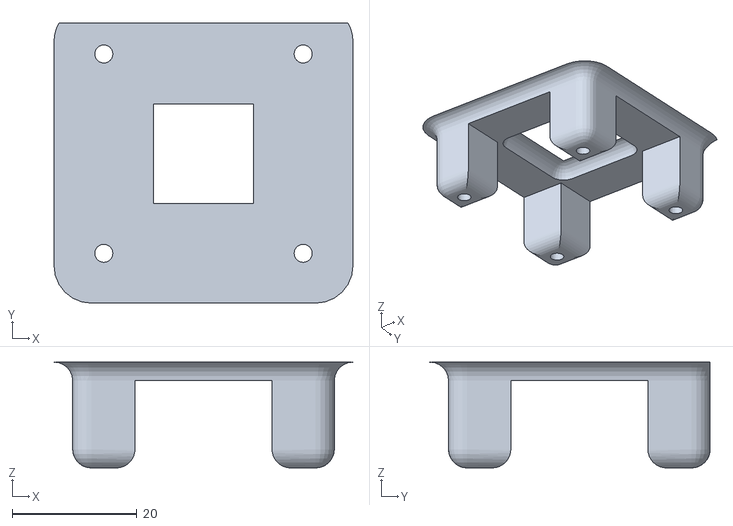
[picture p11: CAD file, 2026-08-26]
cad/RobotChassis03CasterSupport.stl
48.0 x 45.0 x 17.0

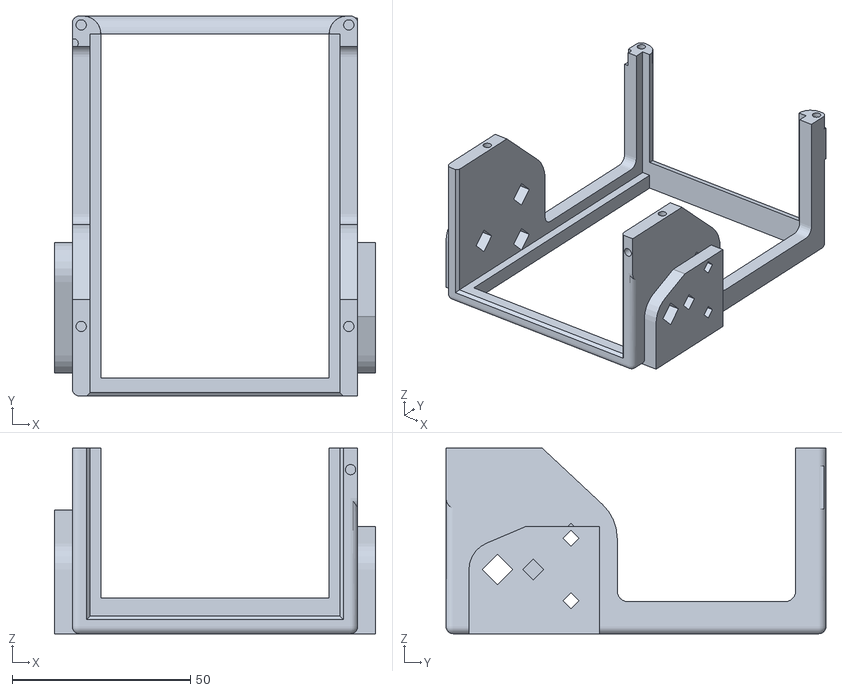
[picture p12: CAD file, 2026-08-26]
cad/RobotChassis03Bottom.stl
90.0 x 106.5 x 52.0

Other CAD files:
cad/RobotChassis03Split.dwg
cad/RobotChassis03.stl

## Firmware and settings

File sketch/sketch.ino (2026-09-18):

#include <Arduino.h>
#include <Arduino_RouterBridge.h>
#include <Arduino_Modulino.h>
#include <Wire.h>
#include "SmoothCompass.h"
#include "SmoothDistance.h"
#include "SmoothMovement.h"
#include "LedMatrixDisplay.h"
#include "RobotMotors.h"
#include "CompassCalibration.h"
#include "MotorCalibration.h"
#include "CombinedCalibration.h"
#include "CompassMode.h"
#include "MonitorFormat.h"


// Sentinel distance used when the distance sensor has no usable reading.
#define INFINITE_DISTANCE 1000000
// Status output interval while the robot is stationary.
#define STATUS_TIMESPAN_WHEN_NOT_MOVING_MS 2000
// Status output interval while the robot is moving. Also gates _monitorDistance's distance-sensor refresh
// cadence (_statusTimeSpan/10) -- at 200ms this made sensor polling too coarse for MotorCalibration's
// turn-measure phases to see a fresh gyro reading in time for their plateau detection, causing spurious e8
// failures on real hardware; 50ms fixed it (confirmed on-device).
#define STATUS_TIMESPAN_WHEN_MOVING_MS 50

// RPC handler that writes a short message to the LED matrix.
bool show_text(String text);
// RPC handler that sends a movement command to the motors.
bool move(String command);

/// @brief This class encapsulates the main logic of the sketch, managing the distance sensor, movement sensor, LED matrix display, and robot motors. It handles initialization, periodic updates, and communication with external commands through the Arduino Router Bridge.
class SketchClass {
private:
  /// @brief Instance of the SmoothDistance class for managing distance sensor readings.
  SmoothDistance _distance;
  /// @brief Instance of the SmoothMovement class for managing movement sensor readings.
  SmoothMovement _movement;
  /// @brief Instance of the LedMatrixDisplay class for managing the LED matrix display.
  LedMatrixDisplay _ledMatrix;
  /// @brief Instance of the SmoothCompass class for reading robot bearings with relation to Earth.
  SmoothCompass _compass;
  /// @brief Instance of the RobotMotors class for managing the robot's motors.
  RobotMotors _robotMotors;
  /// @brief Drives the motor-powered, gyro-closed-loop compass calibration spin.
  CompassCalibration _calibration;
  /// @brief Drives the motor-powered, gyro-closed-loop motor calibration (straight-line bias + turn power).
  MotorCalibration _motorCalibration;
  /// @brief Runs the motor calibration followed by the compass calibration as one "calibrate" command.
  CombinedCalibration _combinedCalibration;
  /// @brief Continuously displays the compass bearing on the LED matrix (issue #12).
  CompassMode _compassMode;
  /// @brief Time span for status updates, which varies based on whether the robot is moving or not.
  int _statusTimeSpan = STATUS_TIMESPAN_WHEN_NOT_MOVING_MS;

  /// @brief Timestamp of the last status update, used to determine when to perform the next update.
  int _previousTimestamp;
  /// @brief Timestamp of the last distance reading, used to control the frequency of distance updates.
  int _previousDistanceRead;
  
  /// @brief Current logic level used for the built-in LED heartbeat.
  int _hl = HIGH;
  /// @brief Most recently smoothed distance reading in centimeters.
  int _distanceCm = INFINITE_DISTANCE;
  /// @brief Distance threshold that triggers an emergency stop.
  int _minimumDistance = 10;
  /// @brief Whether the distance sensor initialized successfully.
  bool _distanceOk = false;
  /// @brief Whether the compass sensor initialized successfully.
  bool _compassOk = false;
  /// @brief Whether the movement sensor initialized successfully.
  bool _movementOk = false;
  /// @brief Whether the motors initialized successfully.
  bool _motorsOk = false;
  /// @brief Whether the obstacle warning is currently active.
  bool _alreadyAlertedAboutDistance = false;
  /// @brief Whether the startup banner has already been printed.
  bool _alreadyShowedAppName = false;

  /// @brief Prints the current distance sensor status to the monitor.
    void _showDistance() {
      if (_distanceOk)
      {
        Monitor.print(" DST: ");
        monitorPrintLeftJustified(_distanceCm, 3);
        Monitor.print("cm");
      }
      else
      {
          Monitor.print("Distance NOK");
      }  
  }
  
  /// @brief Prints the current smoothed movement sensor status to the monitor.
  void _showMovement() {
    if (_movementOk) {
      // Smoothed acceleration and rotation values for each sensor axis.
      float ax=0,ay=0,az=0,rx=0,ry=0,rz=0;
      _movement.get(&ax, &ay, &az, &rx, &ry, &rz);
      Monitor.print(" ax="); monitorPrintLeftJustified(ax, 6);
      Monitor.print(" ay="); monitorPrintLeftJustified(ay, 6);
      Monitor.print(" az="); monitorPrintLeftJustified(az, 6);
      Monitor.print(" rx="); monitorPrintLeftJustified(rx, 6);
      Monitor.print(" ry="); monitorPrintLeftJustified(ry, 6);
      Monitor.print(" rz="); monitorPrintLeftJustified(rz, 6);
    }
    else
    {
      Monitor.print(" Movement NOK");
    }  
  }
  
  /// @brief Prints the current motor command status to the monitor.
  void _showMotorStatus() {
    Monitor.print(" MOT: ");
    Monitor.print(_robotMotors.getStatus());
  }

  void _showCompass() {
    Monitor.print(" CMP: ");
    Monitor.print(_compass.getError());
    if (_compassOk) {
      Monitor.print(" ");
      monitorPrintLeftJustified(_compass.getDirectionAngle(), 6);
      Monitor.print(" ");
      monitorPrintLeftJustified(_compass.getDirectionBearing(), 3);
    }
  }

  void _monitorDistance(int now) {
    _distanceCm = _distance.getDistanceCm();
    if (now - _previousDistanceRead > _statusTimeSpan / 10)
    {
      // Refresh the distance reading more often than the status output.
      _distanceCm = _distanceCm ? _distanceCm : INFINITE_DISTANCE;
      _previousDistanceRead = now;
      if (!_calibration.isActive() && !_robotMotors.isPointing()) {
        if (_distanceCm < 10) {
          move("stop");
          if (_motorsOk) {
            // Convert the short distance value before displaying it on the matrix.
            char buf[4];
            show_text(String(itoa(_distanceCm, buf, 10)));
          }
          _alreadyAlertedAboutDistance = true;
        }
        else if (_alreadyAlertedAboutDistance) {
          _alreadyAlertedAboutDistance = false;
          if (_motorsOk) {
            show_text("_");
          }
        }
      }
    }
  }

  void _onFeatureStarted() {
    _alreadyAlertedAboutDistance = false;
    _statusTimeSpan = STATUS_TIMESPAN_WHEN_MOVING_MS;
  }

  void _onFeatureStopped() {
    _statusTimeSpan = STATUS_TIMESPAN_WHEN_NOT_MOVING_MS;
  }

  void _showMonitorLine(int now) {
    int timespan = now - _previousTimestamp;
    if (timespan > _statusTimeSpan)
    {
      Monitor.flush();
  
      if (!_alreadyShowedAppName) {
        // Monitor.println many times does not work in setup()
        Monitor.println();
        Monitor.println("=========================== SmoothSensors003...");
        Monitor.println();
        Monitor.flush();
        _alreadyShowedAppName = true;
      }

      monitorPrintLeftJustified(now, 8);
      _hl = (_hl == HIGH) ? LOW : HIGH;
      digitalWrite(LED_BUILTIN, _hl);
      _previousTimestamp = now;

      _showDistance();

      _showMovement();

      _showMotorStatus();

      _showCompass();

      _calibration.showStatus();

      _motorCalibration.showStatus();

      _robotMotors.showPointingStatus();

      _robotMotors.showStraightStatus();

      _compassMode.showStatus();

      Monitor.println();
      Monitor.flush();
      // Compass mode's own display refresh. Deliberately bypasses show_text/showTextImplementation -- that path
      // is the compass-mode cancellation hook, so routing through it would self-cancel every tick.
      _compassMode.showBearing();
    }
  }

public:
  /// @brief Creates a sketch controller with the stationary status interval.
  SketchClass() : _robotMotors(_compass, _movement, _ledMatrix), _calibration(_compass, _movement, _robotMotors, _ledMatrix), _motorCalibration(_robotMotors, _movement, _ledMatrix), _combinedCalibration(_motorCalibration, _calibration), _compassMode(_compass, _ledMatrix) {
    _statusTimeSpan = STATUS_TIMESPAN_WHEN_NOT_MOVING_MS;
  }

  /// @brief Releases the sketch controller resources.
  virtual ~SketchClass() {}

  /// @brief Initializes hardware, the monitor, and RPC handlers.
  void setup() {
    // Initialize the I2C bus, monitor, and built-in LED.
    Wire.begin();
    delay(500);
    Monitor.begin(9600);
    delay(2000);
    Monitor.flush();
    pinMode(LED_BUILTIN, OUTPUT);
    digitalWrite(LED_BUILTIN, _hl);

    // Initialize the sketch controller state and RPC handlers.
    _previousTimestamp = millis();
    Bridge.begin();
    Bridge.provide("show_text", show_text);
    Bridge.provide("move", move);

    // Initialize the distance sensor, movement sensor, LED matrix display, and robot motors.
    _distanceOk = _distance.initialize();
    _movementOk = _movement.initialize();
    _compassOk  = _compass.initialize();
    _ledMatrix.initialize();
    _motorsOk = _robotMotors.initialize();

    // Display the ready status on the LED matrix.
    if (_motorsOk) {
      show_text("rdy");
    } else {
      show_text("e1");
    }
  }

  /// @brief Records sensors and periodically reports status or stops at obstacles.
  void loop() {
    // Current loop timestamp and elapsed time since the last status report.
    int now = millis();

    if (_compassOk) {
      _compass.record();
    }
    
    if (_distanceOk) {
      _distance.record();
    }
  
    if (_movementOk) {
      _movement.record();
    }
  
    if (_combinedCalibration.update(now)) {
      _onFeatureStopped();
    }
    if (_robotMotors.updatePointing(now)) {
      _onFeatureStopped();
    }
    _robotMotors.updateGoingStraight(now);

    _monitorDistance(now);
    _showMonitorLine(now);
  
  }

  /// @brief Writes an RPC text command to the LED matrix.
  bool showTextImplementation(String text)
  {
    // Issue #12: any text destined for the LED matrix ends compass mode. Cancel BEFORE printing so the
    // incoming text wins. This is the only hook needed: CompassCalibration/MotorCalibration/RobotMotors write
    // to _ledMatrix directly (not via show_text) when reporting their own progress/results, but moveImplementation()'s
    // existing cancel chain (which cancels _combinedCalibration and _robotMotors pointing before dispatching any
    // other command) guarantees none of those features can be active while compass mode is -- see the compass_mode
    // dispatch below, placed after that same cancel chain.
    if (_compassMode.isActive()) {
      _compassMode.cancel();
      _onFeatureStopped();
    }
    _ledMatrix.print(text.c_str());
    return true;
  }

  /// @brief Applies an RPC movement command and updates the report interval.
  bool moveImplementation(String command)
  {
    bool alreadyStopped = false;

    // Cancel compass mode before any OTHER command's own display write happens, so this safety property
    // doesn't depend on the Python side always sending show_text before move (which showTextImplementation()'s
    // own hook alone would otherwise rely on) -- self-contained here regardless of caller ordering.
    if (_compassMode.isActive() && command != "compass_mode") {
      _compassMode.cancel();
      _onFeatureStopped();
    }

    if (_combinedCalibration.isActive()) {
      if (command == "calibrate") {
        // Already calibrating: ignore the repeat trigger and let the in-progress sequence continue.
        return true;
      }
      _combinedCalibration.cancel();
      _onFeatureStopped();
      alreadyStopped = true;
    }

    if (_robotMotors.isPointing()) {
      if (_robotMotors.isPointingAt(command)) return true;
      _robotMotors.cancelPointing();
      _onFeatureStopped();
      alreadyStopped = true;
    }

    if (command == "calibrate") {
      bool ok = _combinedCalibration.start();
      if (ok) _onFeatureStarted();
      return ok;
    }

    // Placed after the cancel chain above on purpose: that guarantees no calibration or point-to-bearing
    // feature is active while compass mode runs. Combined with the explicit _compassMode cancellation at
    // the top of this method (for any other command) and showTextImplementation()'s hook (for any other
    // display write, including ones the sketch triggers internally), compass mode's exclusivity doesn't
    // depend on any particular caller's ordering.
    if (command == "compass_mode") {
      bool ok = _compassMode.start();
      if (ok) _onFeatureStarted();
      return ok;
    }

    if (_robotMotors.isBearingCommand(command)) {
      bool ok = _robotMotors.startPointing(command, _calibration.hasSucceededOnce());
      if (ok) _onFeatureStarted();
      return ok;
    }

    if (alreadyStopped && command == "stop") {
      // A cancellation above already stopped the motors (which blocks ~400ms) and called
      // _onFeatureStopped(); avoid stopping twice.
      return true;
    }

    _statusTimeSpan = command == "stop" ? STATUS_TIMESPAN_WHEN_NOT_MOVING_MS : STATUS_TIMESPAN_WHEN_MOVING_MS;
    return _robotMotors.move(command);
  }

  /// @brief Whether the motors initialized successfully.
  bool isMotorOk() { return _motorsOk; }
};

// Global controller used by the Arduino framework callbacks and RPC handlers.
SketchClass sketch;

// Forwards the global text RPC to the sketch controller.
bool show_text(String text)
{
  return sketch.showTextImplementation(text);
}

// Forwards the global movement RPC to the sketch controller.
bool move(String command)
{
  // compass_mode is display-only (never drives motors), so it must not be gated behind motor health --
  // otherwise a robot whose motors failed to initialize could never enter compass mode at all.
  if (!sketch.isMotorOk() && command != "compass_mode")
  {
    show_text("e1");
    return false;
  }
  return sketch.moveImplementation(command);
}

// Arduino framework entry point for one-time sketch initialization.
void setup() {
  sketch.setup();
}

// Arduino framework entry point called repeatedly while the sketch runs.
void loop() {
  sketch.loop();
}

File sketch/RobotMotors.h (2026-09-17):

#ifndef _ROBOT_MOTORS_
#define _ROBOT_MOTORS_ 1
#include <Arduino.h>
#include <Arduino_Modulino.h>
#include <Arduino_RouterBridge.h>
#include "IRobotMotors.h"
#include "ISmoothCompass.h"
#include "ISmoothMovement.h"
#include "ILedMatrixDisplay.h"
#include "MonitorFormat.h"

class RobotMotors : public IRobotMotors
{
private:
  static const uint8_t DRIVE_SPEED = 90;
  static const uint8_t MAX_SPEED_PERCENT   = 100;                                  // ModulinoMotors::setSpeedA/B silently reject >100
  static const uint8_t MAX_STRAIGHT_CORRECTION = MAX_SPEED_PERCENT - DRIVE_SPEED;  // clamp on the live straight-line correction -- headroom above DRIVE_SPEED, ceiling from setSpeedA/B's 100 limit (==10 today)
  static constexpr int STRAIGHT_CORRECTION_INTERVAL_MS = 200; // ~20 loop iterations at the measured ~8-11ms loop period -- longer than SmoothMovement's 16-sample ring buffer refresh time (~130-175ms), so every correction acts on a buffer that's fully refreshed since the last one. Makes the control gain "per second," not "per loop iteration."
  static constexpr float STRAIGHT_DEADBAND_DPS = 3.0f; // same value/idiom as MotorCalibration::RZ_DEADBAND_DPS ("rz is effectively at idle")
  static const int8_t STRAIGHT_CORRECTION_STEP = 1; // one bias unit is ~1.6 dps of yaw authority; deliberately smaller than the deadband so a single step can never carry rz across the deadband and cause chatter/limit-cycling
  static constexpr float TURN_CALIBRATED_MIN_DPS = 10.0f; // "has turn calibration actually run" gate
  static constexpr int MAX_TURN_DURATION_MS = 8000; // sanity ceiling on a single blocking turn pulse -- matches
                                                       // MotorCalibration's own TURN_MAX_DURATION_MS; a computed
                                                       // duration beyond this means the calibration data can't be
                                                       // trusted for this turn, so fall back to the uncalibrated path
                                                       // rather than blindly blocking for an unbounded time.
  ModulinoMotors _motors;
  bool _ok = false;
  String _status = "";
  bool  _straightActive = false;          // a go_ahead/go_back run is currently under live yaw correction
  bool  _straightReversed = false;        // true while the active run is go_back
  float _idleStateRz = 0;                 // issue #10's _idleStateRz -- a DISTINCT member from _idleRz1 (turn calibration, issue #8). Do not merge or reuse either one.
  bool  _idleStateRzCaptured = false;     // false until the first real capture -- guards against trusting the 0.0f default (real gyro zero-rate bias is rarely exactly 0) if go_ahead/go_back is ever the very first move() this boot
  int8_t _straightCorrection = 0;         // ephemeral per-run correction; +ve => wheel A (left) faster. Reset to 0 at the start of each straight run, never persisted across runs.
  int   _straightLastCorrectionAt = 0;
  float _idleRz1 = 0;
  float _minimumRzWhenTurningRight = 0;
  int   _timeInMillisecondsToReachMinimumRzWhenTurningRight = 0;
  int   _timeInMillisecondsToStopWhenTurningRight = 0;
  float _maximumRzWhenTurningLeft = 0;
  int   _timeInMillisecondsToReachMaximumRzWhenTurningLeft = 0;
  int   _timeInMillisecondsToStopWhenTurningLeft = 0;

  static const uint8_t BRAKE_POWER_PERCENT = 50; // % of the just-commanded speed used for the reverse-power braking pulse
  static const int BRAKE_PULSE_MS = 120;         // duration of the reverse-power pulse -- long enough to arrest momentum, short enough not to reverse travel

  bool _lastInvertA = false;
  bool _lastInvertB = false;
  uint8_t _lastSpeedA = 0;
  uint8_t _lastSpeedB = 0;

  // Heading tolerance for "close enough" to a point-to-bearing target, absorbing residual smoothing lag and post-calibration magnetic noise.
  static constexpr float POINT_TOLERANCE_DEGREES = 8.0f;
  // Hard timeout for a point-to-bearing turn, bounding every turn/settle/re-check cycle. Turns are now
  // either an exact blocking timed pulse (calibrated) or the original compass-threshold loop (uncalibrated fallback).
  static constexpr int POINT_TIMEOUT_MS = 20000;
  // Minimum dwell time after stopping before trusting a heading reading, giving the ring buffer time to refill with post-stop samples.
  static constexpr int POINT_SETTLE_MS = 500;

  /// @brief States for a point-to-bearing turn: idle, actively turning, or settling before re-checking heading.
  enum PointState { POINT_IDLE, POINT_TURNING, POINT_SETTLING };
  /// @brief Current state of any in-progress point-to-bearing turn.
  PointState _pointState = POINT_IDLE;
  /// @brief RPC command string for the current point-to-bearing turn (e.g. "point_north"), kept for Monitor output and re-trigger detection.
  String _pointCommand = "";
  /// @brief Target heading, in degrees, for the current point-to-bearing turn.
  float _pointTargetDegrees = 0;
  /// @brief Timestamp when the current point-to-bearing operation started; bounds the whole operation via POINT_TIMEOUT_MS.
  int _pointStartedAt = 0;
  /// @brief Timestamp when the current settle period began.
  int _pointSettleStartedAt = 0;
  /// @brief Loop iterations elapsed during the current settle period; waited until >= SmoothCompass::getSampleCount() before trusting the ring buffer.
  unsigned int _pointSettleSamples = 0;
  /// @brief Signed heading error (degrees) from the previous iteration, used to detect a sign flip (overshoot) between loop iterations.
  float _pointLastError = 0;
  /// @brief Timestamp when the current point-to-bearing turn (drive phase) started.
  int _pointTurnStartedAt = 0;
  /// @brief Precomputed active-drive duration (ms) for the current turn; -1 sentinel = not using a timed cutoff (RobotMotors not yet calibrated for turn rate).
  int _pointTurnDurationMs = -1;

  ISmoothCompass& _compass;
  ISmoothMovement& _movement;
  ILedMatrixDisplay& _display;

  static uint8_t _clamp(int value) { return (uint8_t)constrain(value, 0, MAX_SPEED_PERCENT); }

  void _drive(bool invertA, bool invertB, int speedA, int speedB) {
    uint8_t clampedA = _clamp(speedA);
    uint8_t clampedB = _clamp(speedB);
    _lastInvertA = invertA;
    _lastInvertB = invertB;
    _lastSpeedA = clampedA;
    _lastSpeedB = clampedB;
    _motors.setInvertA(invertA);
    _motors.setInvertB(invertB);
    _motors.setSpeedA(clampedA);
    _motors.setSpeedB(clampedB);
  }
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

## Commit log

2026-07-17 Initial commit: SmoothSensors Arduino UNO Q app
    Adds the App Lab sketch (distance + movement sensor smoothing) and
    Python app scaffold, plus CLAUDE.md project documentation.
    Claude-Session: https://claude.ai/code/session_015FR93tYtg447jQrCH8b5bU
2026-07-17 Add project subagents: architect, writer, reviewer, tester
    Scopes each agent to a distinct stage of the workflow (plan, implement,
    review, verify) with context on this repo's sketch/python architecture.
    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
2026-07-18 Add robot behavior specification (v1 draft)
    Captures hardware BOM, dual-brain (Linux/MCU) architecture split,
    voice command vocabulary, object-following behavior, safety
    interlocks, and LED matrix feedback protocol, worked out
    collaboratively over several rounds of requirements discovery.
    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
2026-07-18 Add chosen motors, reject unsuitable motor battery choice
    Records the TT gear motor kit selection with verified specs (voltage,
    stall/no-load current), the MAX22211 current-drive-regulation
    mitigation for running 3-6V motors from a higher-voltage rail, and
    rejects the proposed WAVYPO 9V battery based on evidence it can't
    sustain motor current draw. Battery choice remains open.
    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
2026-07-18 Settle motor battery on NASTIMA LiFePO4 + UBEC regulator
    Resolves the open motor battery item: NASTIMA 6V 6Ah LiFePO4 pack
    feeding a Hobbywing 5A UBEC regulated to a fixed 6.0V, eliminating
    the need for a software PWM duty-cycle cap. Battery-to-UBEC wiring
    will be a direct soldered cable.
    Claude-Session: https://claude.ai/code/session_01Wzuy7rTuujqS8CZFFaPeUC
2026-08-15 Add parametric FreeCAD chassis, phase 1 plan, and v1 turn/audio spec updates
    - PHASE1.md: break SPEC.md's v1 scope into buildable/testable scenarios,
    covering non-vision commands, audio input, and LED feedback (vision-based
    "find and follow" deferred to phase 2).
    - SPEC.md: drop the magnetometer dependency for v1 turning (dead-reckoned
    from the IMU's gyro Z-rate instead, closed-loop heading deferred),
    mark power/hub/mic components purchased, note the phase-2 tilt-stop
    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
2026-08-26 Adding chassis 3D model and 3D printer files
    [RobotChassis03.3mf, RobotChassis03Bottom.stl, RobotChassis03CasterSupport.stl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]
2026-08-26 Adding class to display text on LED Matrix.
2026-08-27 Recognize four voice commands via Vosk
    Adds VoiceCommands, a grammar-constrained Vosk recognizer listening
    for the wake word "robot" followed by "go ahead", "turn right", "turn
    left", or "stop". Wired into main.py's loop, which currently only
    logs the recognized command -- no LED feedback or motor response yet.
    Claude-Session: https://claude.ai/code/session_01GaW812WW9juy1aeiBtZ8Hg
2026-08-27 Show recognized voice commands on the LED matrix
    Adds an MCU-side show_text RPC method (backed by LedMatrixDisplay)
    and wires it from the Python voice loop: each recognized command
    now displays its short code -- gh, tr, tl, stp -- on the onboard
    LED matrix. Motor response is not wired yet.
    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
    [sketch.ino]
2026-08-27 Drive the Modulino Motors from recognized voice commands
    Adds an MCU-side move RPC method using ModulinoMotors: "go_ahead"
    drives both wheels forward, "turn_right"/"turn_left" pivot in place
    by inverting one side, "stop" halts both motors. Wired from the
    Python voice loop alongside the existing show_text LED call.
    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
    [sketch.ino]
2026-08-27 Fix sketch compile errors: use the Bridge singleton, drop broken RPC stub
    BridgeClass has no default constructor, so the sketch's own `bridge`
    instance failed to build -- switch to the library's ready-to-use
    Bridge singleton (bound to Serial1) and use it for begin()/provide()
    throughout. Also removes the empty get_sensor_values() stub: it
    returned RpcCall with no return statement, which the compiler can't
    deduce, and it was never registered or called from anywhere.
    Verified with `arduino-cli compile -b arduino:zephyr:unoq --profile default sketch`.
    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
    [sketch.ino]
2026-08-27 Capture microphone audio via arecord instead of PyAudio
    App Lab's Python venv (uv-managed on the UNO Q's Linux side) has no
    C compiler available, so PyAudio -- which has no prebuilt wheel for
    linux-aarch64 -- fails to build ("error: [Errno 2] No such file or
    directory: 'gcc'"). Vosk ships a prebuilt wheel and is unaffected.
    Replaces the PyAudio stream with a subprocess running `arecord`
    (ALSA's recording CLI, already anticipated as an option in
    PHASE1.md) piping raw S16_LE PCM directly to the Vosk recognizer --
    no compiled Python extension required.
    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
2026-08-27 Add a network CLI deploy workflow for the UNO Q
    Replaces manual App Lab file copying with scripts/deploy.sh: pushes
    sketch/, python/, and app.yaml to the board over SSH (tar piped
    through ssh, since the board has no rsync), uploads the Vosk model
    once and leaves it alone on later deploys, then runs
    `arduino-app-cli app restart` to compile+flash the sketch and
    restart the Python app in one step.
    Verified end-to-end against the board at 10.0.0.245: sketch compiled
    and flashed via the onboard SWD debug interface, Python app started
    cleanly and loaded the Vosk model from python/model/.
    Updates CLAUDE.md's Commands/Architecture sections to match --
    including removing stale references to the old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
2026-08-27 Point arecord at the USB mic explicitly, not ALSA default
    ALSA's "default" device stays pinned to the board's built-in codec
    (card 0, ArduinoImolaHPH) regardless of what USB audio device is
    plugged in -- confirmed on hardware: the mic enumerated as card 1
    ("USB PnP Sound Device") but arecord kept capturing from card 0
    until the device was named explicitly.
    Adds ARECORD_DEVICE (env-overridable, same pattern as
    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
2026-08-27 Harden deploy.sh against arduino-app-cli restart flakiness
    Observed on hardware: `arduino-app-cli app restart` occasionally
    stops the app and then fails to bring it back up (reporting the app
    is still running, apparently a race/state-tracking issue in the tool
    itself), leaving the deploy in a stopped state. Falls back to an
    explicit stop + start when restart fails.
    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
2026-08-31 Latest fixes to robot. ROBOT WORKING
    [RobotChassis03Split.dwg, RobotChassis03Top.stl, RobotChassis03UsbB.stl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]
2026-09-01 Stopping if distance is less than 10cm.
2026-09-01 Moved motors code to RobotMotors.h
2026-09-01 Refactoring so code for Motors is in RobotMotors.h
2026-09-04 Many small improvements.
    [RobotChassis03Bumper.stl, RobotChassis03Split.dwg]
2026-09-04 Removing denoise, it was adding to many problems.
    [RobotMotors.h, sketch.ino]
2026-09-04 Proper README.md
    [RobotChassis03.3mf, RobotChassis03Split.dwg]
2026-09-08 Adding RobotChassis03.stl, so github users can visualize the chassis.
    [RobotChassis03.stl]
2026-09-08 Document missing files in README (sketch/, python/, scripts/, cad, top-level docs)
2026-09-08 Add hardware-in-the-loop test for the sketch: deploy via deploy.sh/ps1, then verify sensor/motor status via app logs
2026-09-08 Fix sketch hardware test: read MCU Serial output via arduino-app-cli monitor, not app logs
    app logs only carries the Python app's own stdout (confirmed via its --help
    text: "Show the logs of the Python app") -- it never contained the sketch's
    Monitor.print() output, so every MCU-side assertion (boot banner, distance,
    movement, motor status) failed against a real board. Capture MCU Serial via
    the separate 'arduino-app-cli monitor' command instead, concurrently with app
    logs, and point each assertion at the stream that actually carries it.
2026-09-08 Fix sketch hardware test: capture MCU monitor and app logs sequentially, drop unwinnable boot-banner assertion
    Running the two SSH streams concurrently made both password prompts race
    for the same stdin when the board uses password auth, failing one of them
    ("Permission denied, please try again."). Capture them one after another
    instead. Also drop test_mcu_sketch_boots: sketch.ino's boot banner prints
    exactly once, before this script's monitor attaches (monitor has no replay
    buffer), so it can never be reliably observed this way -- the per-second
    DST/ax/MOT status-line tests already prove setup() completed.
2026-09-08 Add scripts/setup_ssh_key.py to set up passwordless SSH access to the board
    deploy.ps1's Copy-SshKeyToBoardIfNeeded generated a key at ./id_ed25519 (a
    location ssh never auto-discovers) and only scp'd the .pub file onto the
    board as a loose file instead of appending it to ~/.ssh/authorized_keys --
    so the key it generated was never actually authorized, and every ssh call
    kept falling back to a password prompt. Replace it with a dedicated,
    idempotent script that does the real ssh-copy-id step: reuses an existing
    unencrypted ~/.ssh/id_ed25519 if present, otherwise generates a dedicated
    key and a ~/.ssh/config Host entry, then appends the public key to the
    board's authorized_keys. Also fixes a s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
2026-09-10 Refactoring sketch.ino so loop is now much shorter.
    [RobotChassis03Split.dwg, RobotChassis03Top.stl, RobotChassis03UsbB.stl]
2026-09-11 Removing explicit audio device naming
2026-09-11 Bringing compass again, not working yet, returning wrong angle
    [SmoothCompass.h, sketch.ino]
2026-09-14 Add motor-driven compass calibration to fix hard-iron bias
    The LIS3MDL magnetometer readings were confirmed (empirically, on real
    hardware: N=111, E=115, S=140, W=146 degrees) to be dominated by a
    hard-iron bias (~3x Earth's field) from onboard magnetic material
    (motors/battery/wiring), limiting headings to a ~40 degree arc instead
    of the full 360.
    Adds a "robot calibrate" voice command that spins the robot in place,
    closing the loop on the IMU's gyro (rz integrated to 380 degrees, 20
    degree overshoot margin, 8s hard timeout, >=300 degrees required for a
    result to be accepted as valid) while tracking raw magnetometer min/max
    to compute hard-iron offset and soft-iron scale. Corrections are a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
    [RobotMotors.h, SmoothCompass.h, sketch.ino]
2026-09-14 Updating README.md to describe the new calibrate command.
2026-09-16 Feature/calibrate motors (#5)
    * First part of robot point to Bearing, not working yet.
    * Refactoring so Compass Calibration is in its own class, also tests to avoid global variables.
    * Adding alias commands for point commands
    * Adding motor calibration.
    * Fix motor calibration/point-to-bearing hardware issues, decompose sketch into interface-based classes
    - Motor calibration: fix e8 failures by tightening the status-loop cadence
    (STATUS_TIMESPAN_WHEN_MOVING_MS) so turn-ramp detection sees fresh gyro
    readings in time.
    - RobotMotors: add active braking (brief reverse-power pulse) on stop to
    arrest motor momentum.
    - MotorCalibration: add RATE_MEASURE/COAST_MEASURE phases to measure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
    [RobotChassis03Split.dwg]
2026-09-17 Feature/turn calibration using yaw (#9)
    - MotorCalibration: add RATE_MEASURE/COAST_MEASURE phases to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
    [MotorCalibration.h, RobotMotors.h, sketch.ino]
2026-09-17 Updating dwg.
    [RobotChassis03Split.dwg]
2026-09-17 Replace one-shot motor bias calibration with live rz correction (#10) (#11)
    go_ahead/go_back still curved after motor calibration because a
    free-swiveling caster's starting orientation is essentially random
    each run, so no fixed calibrated bias could compensate for it.
    - Remove the one-shot straight-line bias calibration (MotorCalibration's
    STRAIGHT phase and RobotMotors' _straightBias) entirely.
    - go_ahead/go_back now capture an idle yaw baseline when they start and
    continuously nudge a per-wheel correction opposite to any live yaw
    deviation while driving, converging on and holding whatever
    correction cancels the current run's drift.
    - turn_right/turn_left revert to symmetric DRIVE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
    [MotorCalibration.h, RobotMotors.h, sketch.ino]
2026-09-18 Add compass mode command (#12) (#13)
    "Robot compass mode" continuously shows the compass bearing on the LED
    matrix, refreshing at the STATUS_TIMESPAN_WHEN_MOVING_MS cadence
    already used for status updates. It stops the instant any other text
    is shown on the LED matrix -- obstacle alerts, calibration progress,
    point-to-bearing results, or any other voice command -- via a hook in
    showTextImplementation() plus an explicit cancel for any other move
    command, so the invariant doesn't depend on caller ordering. It also
    works even if the motors failed to initialize, since it never drives
    them.
    Also: deploy.sh/deploy.ps1 now clear any zero-byte (corrupted) cached
    build objects before restarting the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
    [sketch.ino]
2026-09-24 Adding FreeCAD generator for top plate for robots that already have chassis.
    [top_plate-base_box.stl, top_plate.FCStd, top_plate.csv]
